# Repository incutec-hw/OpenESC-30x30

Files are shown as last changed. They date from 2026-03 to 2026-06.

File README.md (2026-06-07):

# OpenESC-30x30

Open-source 4-in-1 BLDC ESC with a 30.5 × 30.5 mm mounting pattern, built around four independent AT32F421 motor controllers running AM32. Six-layer, DShot over the standard 8-pin connector. Designed in KiCad for JLCPCB assembly.

<p>
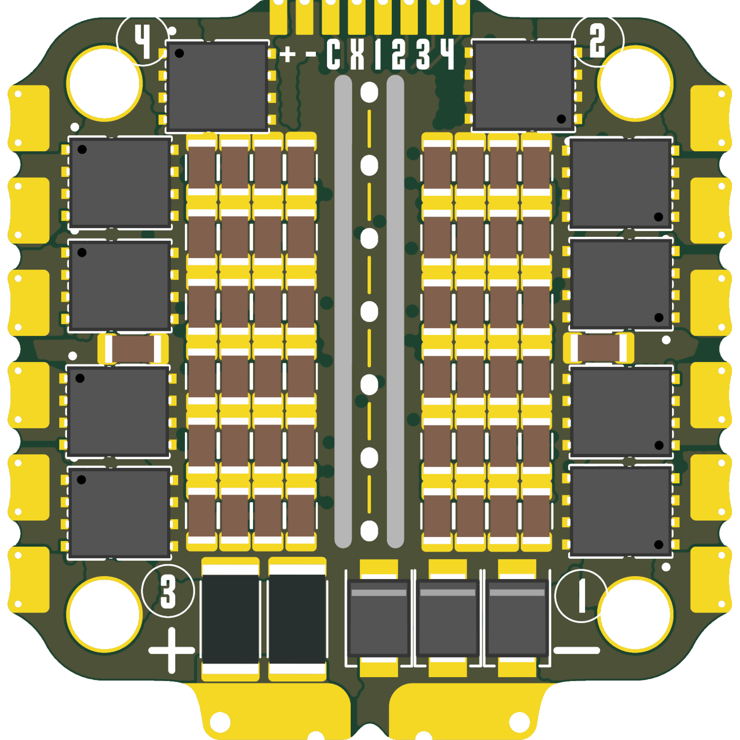
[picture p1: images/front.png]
OpenESC-30x30 top

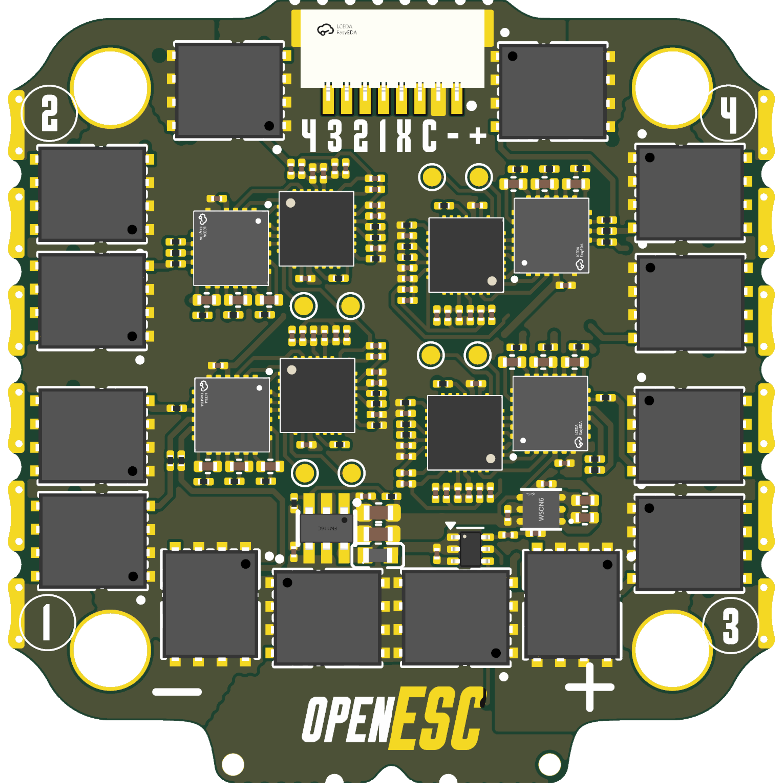
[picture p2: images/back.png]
OpenESC-30x30 bottom

</p>

Part of the incutec OpenDrone line (`incutec-hw/OpenESC-30x30`).

> A smaller **[OpenESC_20X20](https://github.com/incutec-hw/OpenESC_20X20)** (20×20 mm) shares this design and mirrors this repo. The two differ only in board/mounting size and a few power-stage parts.

## Architecture

Four fully independent ESC channels share a common power input and telemetry connector. Each channel has its own MCU and gate driver; the high-current stage is six MOSFETs per channel (three half-bridges). This is the distributed-MCU AM32 4-in-1 topology rather than a single-MCU design. Values below are extracted from the KiCad design files (`hardware/4in1.kicad_sch`, `hardware/ESC.kicad_sch`, `hardware/4in1.kicad_pcb`) and the production BOM (`hardware/production/Rev1-30x30_bom.csv`).

| Block | Part | LCSC | Per board |
|---|---|---|---|
| Motor MCU | AT32F421G8U7 (QFN-28) | C2765098 | 4 |
| Gate driver | NSG2065Q (QFN-24) | C41414478 | 4 |
| Power MOSFETs | SP40N01GHNK PDFN-8L (5×6) | C22385416 | 24 (6 per channel) |

## Specifications

| Parameter | Value |
|---|---|
| Channels | 4 independent BLDC channels |
| MCU | AT32F421G8U7 (ARM Cortex-M4, QFN-28), one per channel |
| Gate driver | NSG2065Q (QFN-24, FD6288Q-compatible), one per channel |
| Power MOSFETs | SP40N01GHNK, N-channel, PDFN-8L (5×6), 24 total (XRS280N03C selected as drop-in next-gen — not yet swapped) |
| Current sense | Board-level high-side: INA186A3IDCKR (100 V/V, SC-70-6) across 2× 0.2 mΩ 2512 shunts in parallel (0.1 mΩ) in the +BATT feed → 10 mV/A → ~330 A full-scale at 3.3 V ADC |
| Input | +BATT direct from connector/pads, 3S–6S |
| Input protection | 3× SMBJ24A TVS (24 V standoff) |
| Buck regulator | LMR54406DBVR (SOT-23-6) + FTC160808S4R7MBCA 4.7 µH inductor → +10 V gate-drive rail (FB 115k/10k, Vref 0.8 V → 10.0 V) |
| LDO | TLV76733DRVR (WSON-6) → +3V3 (MCUs, sensing), from +10 V |
| Signal protocol | DShot (4 independent signal lines, one per channel) |
| Firmware | AM32 (per-channel AT32F421 target, flashed individually) |
| PCB | 6-layer, 1.69 mm |
| Mounting pattern | 30.5 × 30.5 mm, 4× Ø4.0 mm holes (M3) |

Current/voltage ratings are not printed on the design files. The input clamp is set by the SMBJ24A TVS (24 V standoff → 3S–6S); the MOSFET (SP40N01GHNK) and current-sense full-scale (~330 A) set the practical envelope. Characterize before quoting a hard rating.

## Connector

8-pin JST **SM08B-SRSS-TB** (J1). Pin-to-net mapping extracted from the schematic (net labels at the connector pins):

| Pin | Net | Function |
|---|---|---|
| 1 | +BATT | Battery positive |
| 2 | GND | Ground |
| 3 | /CURR | Current-sense telemetry (INA186 output) |
| 4 | *(unconnected)* | No dedicated telemetry pin — telemetry handled by extended DShot |
| 5 | /M1 | DShot signal, channel 1 |
| 6 | /M2 | DShot signal, channel 2 |
| 7 | /M3 | DShot signal, channel 3 |
| 8 | /M4 | DShot signal, channel 4 |

Connector ground returns on the shield/mounting pads P1/P2 (both GND). The same eight signals are also broken out as direct solder pads (U3). Pin 4 — the dedicated telemetry pin on the Betaflight 8-pin standard — is intentionally unconnected: ESC→FC telemetry is carried over the motor signal lines via the bidirectional **extended DShot** protocol.

## Variants and revisions

| File | Description |
|---|---|
| `hardware/4in1.kicad_pro` / `.kicad_pcb` / `.kicad_sch` | Main design (30×30). |
| `hardware/4in1-panel.kicad_pro` / `.kicad_pcb` | Panelized version for production fabrication. |

This repo is the 30×30 member of the OpenESC family; the 20×20 sibling lives in [`OpenESC_20X20`](https://github.com/incutec-hw/OpenESC_20X20). Production exports in `hardware/production/` are versioned `V0.1`–`V0.4` and `Rev1`. `Rev1-30x30` is the 30×30-only fabrication set; `Rev1-30x3020x20` is a combined shared-fab set produced alongside the mini.

## Firmware

[AM32](https://github.com/AlkaMotors/AM32-MultiRotor-ESC-firmware) — incutec's default ESC firmware. Boards ship with the AM32 bootloader pre-loaded; firmware is flashed and configured in-browser at [am32.ca](https://am32.ca). Each channel's AT32F421G8U7 is an independent AM32 target. The AT32F421 + NSG2065Q per-channel topology and the DShot signal nets are the standard AM32 4-in-1 hardware target. Works with Betaflight and other DShot-capable flight controllers.

## Repository structure

```
README.md  LICENSE  CLAUDE.md            Repo root: docs + license + agent instructions
images/                                  Board render images
licensing/                               Hardware license, third-party notices, trademark policy
hardware/                                KiCad 9 project (everything to build/fab the board)
├── 4in1.kicad_sch                       Top schematic (power, current sense, connector)
├── ESC.kicad_sch                        Single ESC channel sheet (instantiated 4×)
├── 4in1.kicad_pcb                       Main board layout (6-layer)
├── 4in1.kicad_pro                       Main project
├── 4in1-panel.kicad_pcb / .kicad_pro    Panelized layout/project for production
├── components.kicad_sym                 Project-local symbol library
├── 4in1ESC-30x30.pretty/                Project-local footprints
├── 4in1ESC-30x30.3dshapes/             3D models (STEP)
├── fp-lib-table / sym-lib-table         Project-local library tables (${KIPRJMOD})
├── 4in1.step / 4in1.glb                 Exported board 3D models
├── production/                          JLCPCB fabrication exports (gerbers, BOM, CPL) per revision
├── fabrication-toolkit-options.json     KiCad Fabrication Toolkit settings
├── cost-analysis.md                     JLCPCB 500-unit cost breakdown (predates latest BOM)
└── database/                            Component analysis notes
```

## License

Hardware: [CERN-OHL-S-2.0](https://ohwr.org/cern_ohl_s_v2.txt). See [LICENSE](LICENSE), [licensing/THIRD_PARTY.md](licensing/THIRD_PARTY.md), and [licensing/TRADEMARKS.md](licensing/TRADEMARKS.md). Some bundled 3D model assets carry their own upstream notices (CC-BY-SA-4.0 / GPL).

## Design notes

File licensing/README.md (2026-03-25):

# Licensing Notes

This folder collects the repository-specific licensing and branding notes that sit alongside the root [LICENSE](../LICENSE) file.

Repository scope:

- Open 4-in-1 AM32 ESC 30x30 hardware design files
- local footprints, symbols, and manufacturing data included in this repository

Primary project hardware license:

- `CERN-OHL-S-2.0` for the primary Open 4-in-1 AM32 ESC 30x30 design and associated original project files

Related notes:

- [TRADEMARKS.md](TRADEMARKS.md) for branding and source-identifying use
- [THIRD_PARTY.md](THIRD_PARTY.md) for bundled upstream asset notices

The main `LICENSE` stays at the repository root so GitHub can detect the primary project license correctly.

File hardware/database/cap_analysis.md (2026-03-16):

# 10µF 50V 1206 MLCC — Cost & Performance Analysis

## Context
- 60× 1206 caps on the 30x30 board (MOSFET bulk decoupling on +BATT rail)
- Operating voltage: 11.1–25.2V (3S–6S LiPo)
- Current part: GCM31CD71H106KE36L (Murata X7T, C5119295)
- All caps derate heavily at 25V DC bias — dielectric type matters less than expected

## DC Bias Reality (25V bias on 50V-rated 1206 10µF)

Samsung published data from their product tool (measured at 1kHz, 25°C):
- **X5R 10µF 50V 1206**: -87% → ~1.3µF effective
- **X7R 10µF 50V 1206**: -78% → ~2.2µF effective

Murata X7T performs similarly per Stan's assessment — expect ~2–3µF effective at 25V.
Bottom line: **all 10µF 50V 1206 MLCCs give only ~2–3µF at operating voltage.**

## Candidate Parts — 10µF 50V 1206

| LCSC | MPN | Mfg | Dielectric | Stock | Basic | Qty 5 | Qty 60 | Qty 500 | 60× cost |
|---|-----|-----|---|---|---|---|---|---|---|
| C5119295 | GCM31CD71H106KE36L | Murata | X7T | 2,319 | No | $0.342 | $0.342 | $0.279 | **$20.52** |
| C89632 | CL31B106KBHNNNE | Samsung | X7R | 1,011,829 | No | $0.051 | $0.051 | $0.041 | **$3.07** |
| C303950 | 1206B106K500NT | FH | X7R | 388,847 | No | $0.068 | $0.068 | $0.055 | **$4.07** |
| C5449000 | TCC1206X7R106K500HT | CCTC | X7R | 44,779 | No | $0.038 | $0.038 | $0.031 | **$2.30** |
| **C13585** | **CL31A106KBHNNNE** | **Samsung** | **X5R** | **3,941,714** | **Yes** | **$0.028** | **$0.028** | — | **$1.67** |

## Current 0805 Part for Reference

| LCSC | MPN | Mfg | Dielectric | Stock | Basic | 60× cost |
|---|-----|-----|---|---|---|---|
| C440198 | GRM21BR61H106KE43L | Murata | X5R | 5,318,712 | Yes | $3.49 |

Note: 0805 has worse DC bias than 1206 (smaller dielectric volume).

## Recommendation

**C13585 (CL31A106KBHNNNE)** — Samsung X5R 10µF 50V 1206

- **$1.67 for 60 pcs** vs $20.52 for Murata X7T → **12× cheaper**
- 3.9M stock — no supply risk
- **JLCPCB basic part** — no $3 extended setup fee per unique part
- DC bias performance: ~1.3µF at 25V — slightly worse than X7R's ~2.2µF
- For bulk MOSFET decoupling, absolute capacitance matters less than ESR/ESL

If the extra ~1µF effective capacitance from X7R matters:
**C89632 (CL31B106KBHNNNE)** — Samsung X7R, $3.07 for 60, 1M stock, extended part

## Total BOM Impact (60 caps)

| Option | Part cost | Setup fee | Total | vs Murata X7T |
|---|---|---|---|---|
| GCM31CD71H106KE36L (current) | $20.52 | $3.00 | $23.52 | baseline |
| CL31A106KBHNNNE (X5R basic) | $1.67 | $0.00 | **$1.67** | **saves $21.85** |
| CL31B106KBHNNNE (X7R ext) | $3.07 | $3.00 | $6.07 | saves $17.45 |
| TCC1206X7R106K500HT (X7R ext) | $2.30 | $3.00 | $5.30 | saves $18.22 |

## SMBJ26A TVS Diode Alternative

Current: C908802 (GOODWORK) — 208 pcs at JLCPCB assembly, 190 shortfall, extended, €0.65

| LCSC | MPN | Mfg | Stock | Price | Notes |
|---|-----|-----|---|---|---|
| **C123820** | SMBJ26A | MDD | 22,554 | $0.051 | Best stock, reliable mfg |
| C353371 | SMBJ26A | Shandong Jingdao | 12,930 | $0.034 | Cheapest |
| C315992 | SMBJ26A | Littelfuse | 4,296 | $0.086 | Brand name |

All are identical spec: 26V standoff, 28.9V breakdown, 42.1V clamp, 600W peak, SMB package.
Recommend **C123820** (MDD) — 22k+ stock, $0.051, proven JLCPCB supplier.

---
*Generated 2026-03-15*

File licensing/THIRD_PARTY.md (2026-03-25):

# Third-Party Assets

This repository's main hardware design is licensed under `CERN-OHL-S-2.0`, but some bundled assets may retain their own upstream notices or licenses.

Known third-party-licensed assets observed in the current repo state:

- `4in1ESC-30x30.3dshapes/IND-SMD_L1.6-W0.8_FTC160865SR47MBCA.step`
  - contains an embedded `CC-BY-SA 4.0` notice and KiCad exception text in the file header
- `4in1ESC-30x30.3dshapes/QFN-28_L4.0-W4.0-P0.40-TL-EP2.4.step`
  - contains an embedded GNU General Public License notice in the file header

Practical rule:

- embedded upstream notices in individual third-party files remain relevant for those files
- the repository-level hardware license does not erase or replace those upstream notices

If more third-party library assets are intentionally bundled later, document them here.

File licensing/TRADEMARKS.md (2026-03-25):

# Trademarks And Branding

The primary Open 4-in-1 ESC 30x30 hardware design in this repository is licensed under `CERN-OHL-S-2.0`.

Some bundled third-party assets may carry separate upstream notices. See [THIRD_PARTY.md](THIRD_PARTY.md).

That hardware license does **not** grant permission to use any project names, logos, packaging, product branding, or other source-identifying presentation from this repository in a way that implies official status, endorsement, certification, or authorization.

This means you may:

- make, modify, and sell hardware based on the licensed design files, subject to the repository license
- use factual, non-confusing descriptive statements about compatibility or design origin

This means you may not, without separate written permission:

- present your product as an official or authorized version of this project
- use project logos or branded packaging
- market your product in a way that is likely to confuse customers about who made it, tested it, certified it, or supports it

Examples of descriptive use that are generally acceptable:

- `based on the Open 4-in-1 AM32 ESC design`
- `compatible with the 30x30 Open 4-in-1 AM32 ESC layout`

Any permission to use branding for an official product, reseller arrangement, or certification program is separate from the open hardware license.

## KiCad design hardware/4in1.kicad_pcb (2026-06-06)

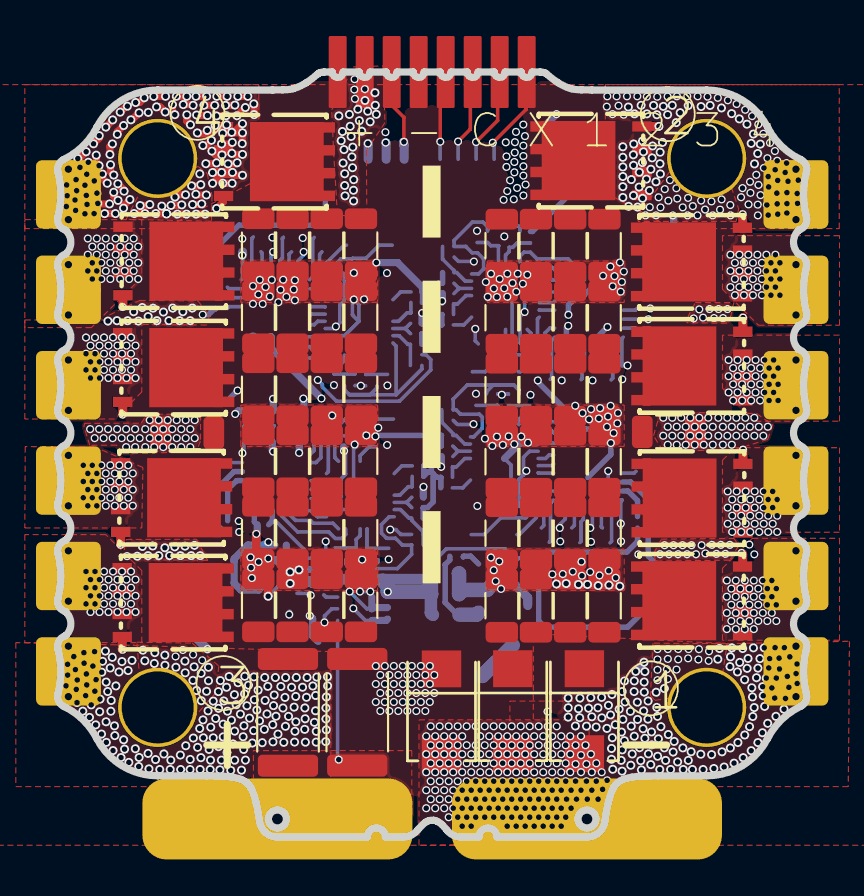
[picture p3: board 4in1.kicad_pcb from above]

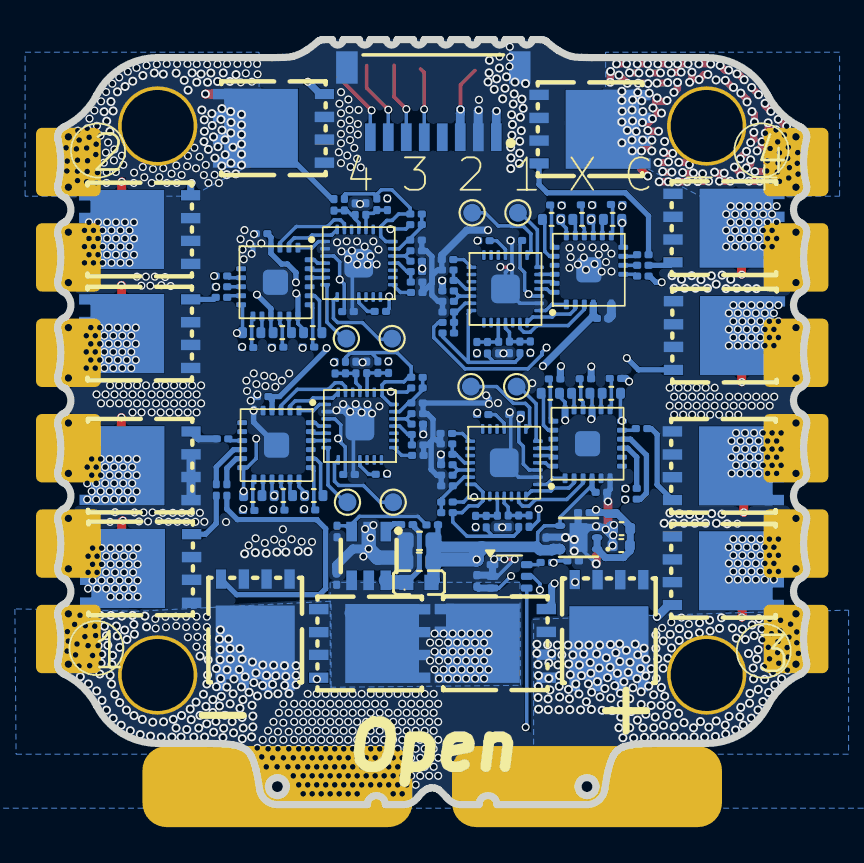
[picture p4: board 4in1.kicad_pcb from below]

Board: 6 copper layers, 41.6 x 42.5 mm, 218 parts (152 on the bottom side), 150 nets.

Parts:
C2, C3, C6, C6#2, C6#3, C7, C8, C9, C13, C14, C15, C16, C17, C18, C19, C20, C24, C25, C26, C27, C28, C29, C30, C31, C43, C44, C45, C69, C70, C71, C72, C79, C80, C82, C83, C84, C85, C87, C88, C95, C96, C97, C98, C99, C100, C101, C105, C106, C107, C108: 10uF; C_1206_3216Metric
C4, C51: 22uF; C_0402_1005Metric
C32, C33, C34, C35, C36, C37, C38, C39, C53, C56, C62, C67: 100nF; C_0402_WIDE
C47, C86: 22uF; C_0603_1608Metric
C48, C49, C50, C52, C54, C55, C57, C58, C59, C60, C61, C63, C64, C65, C66, C68, C74, C75, C76, C81, C93, C94: 100nF; C_0201_0603Metric
D1, D2, D3: SMBJ24A; SMB_L4.5-W3.7-LS5.4-RD
J1: SM08B-SRSS-TB; JST_SM08B-SRSS-TB
Q1, Q2, Q3, Q4, Q5, Q6, Q7, Q8, Q9, Q10, Q11, Q12, Q13, Q14, Q15, Q16, Q17, Q18, Q19, Q20, Q21, Q22, Q23, Q24: C22385416; PDFN-8L_L6.0-W5.0-P1.27
R10, R12, R13, R15, R25, R27, R28, R30, R31, R33, R34, R36, R46, R48, R49, R51, R52, R54, R64, R66, R67, R69, R70, R72: 10k; C_0201_0603Metric
R11, R14, R26, R29, R32, R35, R47, R50, R53, R65, R68, R71, R73: 1k; C_0201_0603Metric
R18, R19, R21, R22, R40, R41, R58, R59, R121: 10k; R_0201_0603Metric
R20, R39, R57, R87: 220R; R_0201_0603Metric
R23, R24, R37, R38, R42, R43, R44, R45, R55, R56, R60, R61, R62, R63, R74, R75, R76, R77, R78, R79, R80, R81, R82, R83: 15R; R_0201_0603Metric
R84, R85, R86, R88: 10R; R_0201_0603Metric
R120: 115k; R_0201_0603Metric
Rsense1, Rsense2: 0.2mR; R_2512_6332Metric
TP1, TP2, TP3, TP4, TP5, TP6, TP7, TP8: TestPoint; TestPoint_Pad_D1.0mm
U2, U5, U7, U9: AT32F421G8U7; QFN-28_L4.0-W4.0-P0.40-TL-EP2.4
U3: 4in1ESC30x30
U4, U6, U8, U10: NSG2065Q; QFN-24_L4.0-W4.0-P0.50-TL-EP2.8
U12: INA186A3IDCKR; SOT-363_SC-70-6
U13: LMR54406DBVR; SOT-23-6_L2.9-W1.6-P0.95-LS2.8-BR
U14: FTC160808S4R7MBCA; IND-SMD_L1.6-W0.8_FTC160865SR47MBCA
U15: TLV76733DRVR; WSON-6_L2.0-W2.0-P0.65-TL-EP

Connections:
+3V3: C4.2, C49.1, C51.2, C55.1, C61.1, C66.1, C81.1, C93.1, R18.2, R21.2, R40.2, R58.2, R84.2, R85.2, R86.2, R88.2, U2.17 (VDD), U5.17 (VDD), U7.17 (VDD), U9.17 (VDD), U12.3 (VS), U15.1 (OUT), U15.2 (FB/SNS)
+10V: C47.1, C57.1, C58.1, C63.1, C68.1, C76.1, C86.1, R120.1, U4.4 (VCC), U6.4 (VCC), U8.4 (VCC), U10.4 (VCC), U14.2, U15.4 (EN), U15.6 (IN)
+BATT: C2.1, C3.1, C6.1, C6#2.1, C6#3.1, C7.1, C8.1, C9.1, C13.1, C14.1, C15.1, C16.1, C17.1, C18.1, C19.1, C20.1, C24.1, C25.1, C26.1, C27.1, C28.1, C29.1, C30.1, C31.1, C43.1, C44.1, C45.1, C69.1, C70.1, C71.1, C72.1, C74.1, C79.1, C80.1, C82.1, C83.1, C84.1, C85.1, C87.1, C88.1, C95.1, C96.1, C97.1, C98.1, C99.1, C100.1, C101.1, C105.1, C106.1, C107.1, C108.1, D1.1, D2.1, D3.1, J1.1, Q1.3 (D), Q6.3 (D), Q7.3 (D), Q8.3 (D), Q9.3 (D), Q10.3 (D), Q13.3 (D), Q16.3 (D), Q17.3 (D), Q18.3 (D), Q19.3 (D), Q20.3 (D), Rsense1.2, Rsense2.2, U3.3 (VBAT+), U12.5 (-IN), U13.4 (EN), U13.5 (VIN)
/CSA+: Rsense1.1, Rsense2.1, U3.1 (VBAT), U12.4 (+IN)
/CURR: C94.1, J1.3, R73.1, U3.5 (CUR)
/ESC1/AH: U2.20 (PA10), U4.22 (HIN1)
/ESC1/AL: U2.15 (PB1), U4.1 (LIN1)
/ESC1/BH: U2.19 (PA9), U4.23 (HIN2)
/ESC1/BL: U2.14 (PB0), U4.2 (LIN2)
/ESC1/CH: U2.18 (PA8), U4.24 (HIN3)
/ESC1/CL: U2.13 (PA7), U4.3 (LIN3)
/ESC1/FBA: R25.1, R26.2, R27.2, U2.6 (PA0)
/ESC1/FBB: R28.2, R29.2, R30.2, U2.10 (PA4)
/ESC1/FBC: R31.2, R32.2, R33.2, U2.11 (PA5)
/ESC1/FBCOMMON: R25.2, R28.1, R31.1, U2.7 (PA1)
/ESC1/GHA: R76.1, U4.19 (HO1)
/ESC1/GHB: R55.1, U4.16 (HO2)
/ESC1/GHC: R23.1, U4.13 (HO3)
/ESC1/GLA: R80.1, U4.11 (LO1)
/ESC1/GLB: R62.1, U4.10 (LO2)
/ESC1/GLC: R42.1, U4.9 (LO3)
/ESC1/MotorA: C53.1, Q1.1 (S), Q2.3 (D), R27.1, U3.23 (1A), U4.18 (VS1)
/ESC1/MotorB: C32.1, Q6.1 (S), Q11.3 (D), R30.1, U3.22 (1B), U4.15 (VS2)
/ESC1/MotorC: C36.1, Q16.1 (S), Q21.3 (D), R33.1, U3.21 (1C), U4.12 (VS3)
/ESC1/vdda: C48.1, R84.1, U2.5 (VDDA)
/ESC2/AH: U5.20 (PA10), U6.22 (HIN1)
/ESC2/AL: U5.15 (PB1), U6.1 (LIN1)
/ESC2/BH: U5.19 (PA9), U6.23 (HIN2)
/ESC2/BL: U5.14 (PB0), U6.2 (LIN2)
/ESC2/CH: U5.18 (PA8), U6.24 (HIN3)
/ESC2/CL: U5.13 (PA7), U6.3 (LIN3)
/ESC2/FBA: R10.1, R11.2, R12.2, U5.6 (PA0)
/ESC2/FBB: R13.2, R14.2, R15.2, U5.10 (PA4)
/ESC2/FBC: R34.2, R35.2, R36.2, U5.11 (PA5)
/ESC2/FBCOMMON: R10.2, R13.1, R34.1, U5.7 (PA1)
/ESC2/GHA: R77.1, U6.19 (HO1)
/ESC2/GHB: R56.1, U6.16 (HO2)
/ESC2/GHC: R24.1, U6.13 (HO3)
/ESC2/GLA: R81.1, U6.11 (LO1)
/ESC2/GLB: R63.1, U6.10 (LO2)
/ESC2/GLC: R43.1, U6.9 (LO3)
/ESC2/MotorA: C56.1, Q3.3 (D), Q7.1 (S), R12.1, U3.20 (2B), U6.18 (VS1)
/ESC2/MotorB: C33.1, Q8.1 (S), Q12.3 (D), R15.1, U3.19 (2C), U6.15 (VS2)
/ESC2/MotorC: C37.1, Q17.1 (S), Q22.3 (D), R36.1, U3.18 (2A), U6.12 (VS3)
/ESC2/vdda: C54.1, R85.1, U5.5 (VDDA)
/ESC3/AH: U7.20 (PA10), U8.22 (HIN1)
/ESC3/AL: U7.15 (PB1), U8.1 (LIN1)
/ESC3/BH: U7.19 (PA9), U8.23 (HIN2)
/ESC3/BL: U7.14 (PB0), U8.2 (LIN2)
/ESC3/CH: U7.18 (PA8), U8.24 (HIN3)
/ESC3/CL: U7.13 (PA7), U8.3 (LIN3)
/ESC3/FBA: R46.1, R47.2, R48.2, U7.6 (PA0)
/ESC3/FBB: R49.2, R50.2, R51.2, U7.10 (PA4)
/ESC3/FBC: R52.2, R53.2, R54.2, U7.11 (PA5)
/ESC3/FBCOMMON: R46.2, R49.1, R52.1, U7.7 (PA1)
/ESC3/GHA: R78.1, U8.19 (HO1)
/ESC3/GHB: R60.1, U8.16 (HO2)
/ESC3/GHC: R37.1, U8.13 (HO3)
/ESC3/GLA: R82.1, U8.11 (LO1)
/ESC3/GLB: R74.1, U8.10 (LO2)
/ESC3/GLC: R44.1, U8.9 (LO3)
/ESC3/MotorA: C62.1, Q4.3 (D), Q13.1 (S), R48.1, U3.15 (3B), U8.18 (VS1)
/ESC3/MotorB: C34.1, Q9.1 (S), Q14.3 (D), R51.1, U3.16 (3C), U8.15 (VS2)
/ESC3/MotorC: C38.1, Q18.1 (S), Q23.3 (D), R54.1, U3.17 (3A), U8.12 (VS3)
/ESC3/vdda: C60.1, R86.1, U7.5 (VDDA)
/ESC4/AH: U9.20 (PA10), U10.22 (HIN1)
/ESC4/AL: U9.15 (PB1), U10.1 (LIN1)
/ESC4/BH: U9.19 (PA9), U10.23 (HIN2)
/ESC4/BL: U9.14 (PB0), U10.2 (LIN2)
/ESC4/CH: U9.18 (PA8), U10.24 (HIN3)
/ESC4/CL: U9.13 (PA7), U10.3 (LIN3)
/ESC4/FBA: R64.1, R65.2, R66.2, U9.6 (PA0)
/ESC4/FBB: R67.2, R68.2, R69.2, U9.10 (PA4)
/ESC4/FBC: R70.2, R71.2, R72.2, U9.11 (PA5)
/ESC4/FBCOMMON: R64.2, R67.1, R70.1, U9.7 (PA1)
/ESC4/GHA: R79.1, U10.19 (HO1)
/ESC4/GHB: R61.1, U10.16 (HO2)
/ESC4/GHC: R38.1, U10.13 (HO3)
/ESC4/GLA: R83.1, U10.11 (LO1)
/ESC4/GLB: R75.1, U10.10 (LO2)
/ESC4/GLC: R45.1, U10.9 (LO3)
/ESC4/MotorA: C67.1, Q5.3 (D), Q19.1 (S), R66.1, U3.12 (4A), U10.18 (VS1)
/ESC4/MotorB: C35.1, Q10.1 (S), Q15.3 (D), R69.1, U3.13 (4B), U10.15 (VS2)
/ESC4/MotorC: C39.1, Q20.1 (S), Q24.3 (D), R72.1, U3.14 (4C), U10.12 (VS3)
/ESC4/vdda: C65.1, R88.1, U9.5 (VDDA)
/M1: J1.5, R20.1, U3.7 (M1)
/M2: J1.6, R39.1, U3.8 (M2)
/M3: J1.7, R57.1, U3.9 (M3)
/M4: J1.8, R87.1, U3.10 (M4)
GND: C2.2, C3.2, C4.1, C6.2, C6#2.2, C6#3.2, C7.2, C8.2, C9.2, C13.2, C14.2, C15.2, C16.2, C17.2, C18.2, C19.2, C20.2, C24.2, C25.2, C26.2, C27.2, C28.2, C29.2, C30.2, C31.2, C43.2, C44.2, C45.2, C47.2, C48.2, C49.2, C50.2, C51.1, C52.2, C54.2, C55.2, C57.2, C58.2, C59.2, C60.2, C61.2, C63.2, C64.2, C65.2, C66.2, C68.2, C69.2, C70.2, C71.2, C72.2, C74.2, C76.2, C79.2, C80.2, C81.2, C82.2, C83.2, C84.2, C85.2, C86.2, C87.2, C88.2, C93.2, C94.2, C95.2, C96.2, C97.2, C98.2, C99.2, C100.2, C101.2, C105.2, C106.2, C107.2, C108.2, D1.2, D2.2, D3.2, J1.2, J1.P1 (MP1), J1.P2 (MP2), Q2.1 (S), Q3.1 (S), Q4.1 (S), Q5.1 (S), Q11.1 (S), Q12.1 (S), Q14.1 (S), Q15.1 (S), Q21.1 (S), Q22.1 (S), Q23.1 (S), Q24.1 (S), R11.1, R14.1, R19.2, R22.2, R26.1, R29.1, R32.1, R35.1, R41.2, R47.1, R50.1, R53.1, R59.2, R65.1, R68.1, R71.1, R121.2, U2.16 (VSS), U2.29 (VSS), U3.2 (BATGND), U3.4 (GND), U3.11 (Hole), U4.6 (COM), U4.25 (COM), U5.16 (VSS), U5.29 (VSS), U6.6 (COM), U6.25 (COM), U7.16 (VSS), U7.29 (VSS), U8.6 (COM), U8.25 (COM), U9.16 (VSS), U9.29 (VSS), U10.6 (COM), U10.25 (COM), U12.1 (REF), U12.2 (GND), U13.2 (GND), U15.3 (GND), U15.5 (GND), U15.7 (EP)
unnamed: Q1.2 (G), R76.2
unnamed: Q2.2 (G), R80.2
unnamed: Q3.2 (G), R81.2
unnamed: Q4.2 (G), R82.2
unnamed: Q5.2 (G), R83.2
unnamed: Q6.2 (G), R55.2
unnamed: Q7.2 (G), R77.2
unnamed: Q8.2 (G), R56.2
unnamed: Q9.2 (G), R60.2
unnamed: Q10.2 (G), R61.2
unnamed: Q11.2 (G), R62.2
unnamed: Q12.2 (G), R63.2
unnamed: Q13.2 (G), R78.2
unnamed: Q14.2 (G), R74.2
unnamed: Q15.2 (G), R75.2
unnamed: Q16.2 (G), R23.2
unnamed: Q17.2 (G), R24.2
unnamed: Q18.2 (G), R37.2
unnamed: Q19.2 (G), R79.2
unnamed: Q20.2 (G), R38.2
unnamed: Q21.2 (G), R42.2
unnamed: Q22.2 (G), R43.2
unnamed: Q23.2 (G), R44.2
unnamed: Q24.2 (G), R45.2
unnamed: R19.1, U2.1 (BOOT0)
unnamed: C50.1, R18.1, U2.4 (NRST)
unnamed: TP1.1 (1_1), U2.21 (PA13)
unnamed: TP4.1 (1_1), U2.22 (PA14)
unnamed: R20.2, U2.25 (PB4)
unnamed: C53.2, U4.20 (VB1)
unnamed: C32.2, U4.17 (VB2)
unnamed: C36.2, U4.14 (VB3)
unnamed: R22.1, U5.1 (BOOT0)
unnamed: C52.1, R21.1, U5.4 (NRST)
unnamed: TP2.1 (1_1), U5.21 (PA13)
unnamed: TP5.1 (1_1), U5.22 (PA14)
unnamed: R39.2, U5.25 (PB4)
unnamed: C56.2, U6.20 (VB1)
unnamed: C33.2, U6.17 (VB2)
unnamed: C37.2, U6.14 (VB3)
unnamed: R41.1, U7.1 (BOOT0)
unnamed: C59.1, R40.1, U7.4 (NRST)
unnamed: TP3.1 (1_1), U7.21 (PA13)
unnamed: TP6.1 (1_1), U7.22 (PA14)
unnamed: R57.2, U7.25 (PB4)
unnamed: C62.2, U8.20 (VB1)
unnamed: C34.2, U8.17 (VB2)
unnamed: C38.2, U8.14 (VB3)
unnamed: R59.1, U9.1 (BOOT0)
unnamed: C64.1, R58.1, U9.4 (NRST)
unnamed: TP7.1 (1_1), U9.21 (PA13)
unnamed: TP8.1 (1_1), U9.22 (PA14)
unnamed: R87.2, U9.25 (PB4)
unnamed: C67.2, U10.20 (VB1)
unnamed: C35.2, U10.17 (VB2)
unnamed: C39.2, U10.14 (VB3)
unnamed: R73.2, U12.6 (OUT)
unnamed: C75.2, U13.1 (CB)
unnamed: R120.2, R121.1, U13.3 (FB)
unnamed: C75.1, U13.6 (SW), U14.1

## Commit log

2026-03-11 Initial commit: 30x30 variant planning
    Hardware changes documented vs 20x20 variant.
    Key change: NSG20652Q gate driver (different pinout from NSG2065Q).
2026-03-11 Initial project setup from 20x20 variant
    Copied library, schematics, footprints, and 3D models from 20x20 project.
    Updated all paths for 30x30 project naming (footprint prefix, 3D model paths,
    project references). README documents hardware changes (NSG20652Q gate driver,
    SP40N01GHNK MOSFETs, 4-layer 30x30mm PCB).
    [4in1ESC-30x30.kicad_sch, ESC.kicad_sch]
2026-03-11 Sync v0.4 component changes from 20x20 variant
    - INA186A3IDCKR replaces INA199A1DCKR (current sense amp)
    - TLV76733DRVR replaces TPS746 (LDO), SNS wired to output
    - BLM03PX121SN1D ferrite bead on VDDA
    - Add .gitignore for backups and prl files
    [4in1ESC-30x30.kicad_sch, ESC.kicad_sch]
2026-03-14 Prepare for open source: PCB layout, new footprints, 3D models, comprehensive gitignore
    - Add PCB layout (4-layer, 30x30mm)
    - Add SP40N01GHNK MOSFET footprint and 3D model (PDFN-8L 5x6mm)
    - Add NSG20652Q gate driver alt footprint and QFN-24 3D model
    - Add board outline footprint and SMB connector footprint/3D model
    - Update schematic and symbols for NSG20652Q pinout
    - Comprehensive .gitignore matching 20x20 variant
    - Fix README link to 20x20 repo
    [4in1ESC-30x30.kicad_pcb, 4in1ESC-30x30.kicad_sch, ESC.kicad_sch]
2026-03-14 Switch gate driver to NSG2065Q (FD6288Q-compatible) in docs
    NSG20652Q was a dead-end with no pin-compatible alternatives.
    NSG2065Q shares the FD6288Q pinout with 7+ drop-in replacements
    and 27k+ combined LCSC stock. Same driver used in 20x20 variant.
2026-03-14 Update mounting pattern in README.md
2026-03-14 Add PCB render images to README
    Front and back 3D renders of the 30x30 board.
2026-03-16 Final parts changes and production files for V0.1
    [4in1ESC-30x30.kicad_pcb, 4in1ESC-30x30.kicad_sch, V0.1_bom.csv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]
2026-03-18 Replace backordered parts with in-stock LCSC alternatives
    - 10kΩ 0201: C473048 → C106225 (Yageo, 662k stock)
    - Ferrite bead 0201: C525479 → C440127 (330Ω@100MHz, better for VDDA filtering)
    - 220Ω 0201: C473535 → C226468 (Yageo)
    - 10uF cap: C440198 (0805) → C13585 (1206 basic part, Samsung)
    - TVS diode: C908802 → C315992 (Littelfuse SMBJ26A)
    [4in1ESC-30x30.kicad_pcb, 4in1ESC-30x30.kicad_sch, ESC.kicad_sch]
2026-03-25 Standardize repo: .gitignore, README, license, remove production from tracking
    - Standardize .gitignore to match ecosystem template
    - Update README: simplify license section, remove stale status checklist
    - Replace LICENSE stub with full CERN-OHL-S-2.0 text
    - Remove production/ from git tracking (generated, re-exportable)
    - Add previously untracked licensing/ directory
    - Delete empty nextpcb/ directory
    [4in1ESC-30x30.kicad_pcb, 4in1ESC-30x30.kicad_sch, ESC.kicad_sch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]
2026-05-07 alpha routing
    [4in1ESC-30x30.kicad_pcb, 4in1ESC-30x30.kicad_sch, ESC.kicad_sch]
2026-05-29 Migrate off iCloud and rename project to 4in1
    Moved repo from iCloud Drive to ~/OpenDrone/4in1. Renamed core KiCad
    project files (pro/sch/pcb/prl/dru) 4in1ESC-30x30 -> 4in1; updated
    .kicad_pro/.kicad_prl filenames, root sheet name, and the 74 footprint
    sheetfile hints in the PCB. Library dirs (.pretty/.3dshapes) kept as-is.
    Updated README/CLAUDE.md references. Checkpoint before 3D-model path fix.
    [4in1.kicad_pcb, 4in1.kicad_sch, 4in1ESC-30x30.kicad_pcb]
2026-05-29 Fix QFN 3D model paths to project-local 3dshapes
    The 7 QFN footprints (U2/U5/U7/U9 QFN-28, U4/U8/U10 QFN-24) had 3D
    model links inherited from the mini project: ${KIPRJMOD}/4in1ESC.3dshapes/
    or absolute paths into the old iCloud "4in1ESC 2" folder, neither of
    which resolve here. Repointed all to ${KIPRJMOD}/4in1ESC-30x30.3dshapes/
    (files already present) and fixed the same path in the QFN-24-TL-EP2.8
    and QFN-28 library footprints so library updates won't regress it.
    Total broken 3D refs: 0.
2026-06-06 docs: reconcile README to design files, add DESIGN_NOTES
    Reconcile README against schematic net labels and on-canvas comments:
    6-layer (was 4), LMR54406DBVR buck -> +10V (was LMR51420/12V),
    FTC160808 4.7uH inductor, board-level INA186 current sense (2x 0.2mR
    parallel -> ~330A), connector pin 4 unconnected, GND on pads P1/P2,
    drop the 20x20-on-same-layout claim (30x30 only). Note MOSFET Value/LCSC
    field swap (build = SP40N01GHNK/C22385416). Add DESIGN_NOTES.md mirroring
    on-canvas KiCad comments.
2026-06-06 docs: telemetry via extended DShot (pin 4), final canvas sync
2026-06-06 meta: standardize symbol BOM/doc fields (30x30)
    Add MPN/Manufacturer/LCSC/Digi-Key/Mouser/Farnell/Cost to every sourced
    part. Source MPN + LCSC unit cost via keyless LCSC; Manufacturer set for
    known ICs (TI, ArteryTek, Littelfuse). Fix MOSFET Value/LCSC swap
    (Value/MPN=SP40N01GHNK, LCSC=C22385416), clear legacy LCSC_Part, strip
    CJK from Manufacturer. Digi-Key/Mouser/Farnell left blank pending API
    creds. Properties-only — no connectivity change. Also carries the
    finalized on-canvas design comments.
    [4in1.kicad_sch, ESC.kicad_sch]
2026-06-06 pcb: routing snapshot (WIP) before hardware/ restructure
    Snapshot of in-progress PCB routing so the upcoming directory
    restructure can move the file as a clean rename. Routing is still
    in progress.
    [4in1.kicad_pcb]
2026-06-06 docs: refresh board renders (standardized 3D top/bottom)
    [4in1.kicad_pcb, 4in1.kicad_sch, ESC.kicad_sch]
2026-06-06 docs: update paths for hardware/ restructure (30x30)
    Repo restructured to mirror OpenFC-Lite: KiCad project + libs +
    production + design docs moved under hardware/; root keeps README,
    LICENSE, CLAUDE.md, images/, licensing/. Update README structure tree
    and all path references. (CLAUDE.md updated locally; it is git-ignored.)
    The git mv renames themselves were swept into the prior render commit
    79590e2; this commit fixes the doc references.
2026-06-06 docs: show board renders side-by-side (OpenFC-Lite-Mini style)
2026-06-07 docs: via-free board renders
    Re-render top/bottom board images with vias removed for a cleaner look.
    KiCad cannot render tented vias, so vias were temporarily stripped via the
    pcbnew API for rendering only; source .kicad_pcb files are unchanged.
2026-06-07 docs: re-render boards without floor shadows
    Re-render top/bottom images at basic quality so the soldermask floor
    shadow halo is gone. Vias still stripped for the render only (via pcbnew),
    source .kicad_pcb files unchanged.
2026-06-07 docs: render boards without solder paste
    Strip the solder-paste layer (and vias) for the render only so SMD pads
    show as clean copper instead of gray paste deposits. Source .kicad_pcb
    files unchanged.
2026-06-07 docs: remove DESIGN_NOTES, trim README boilerplate
    - Delete DESIGN_NOTES.md (and its gitignore exception)
    - Drop the Manufacturing / production-export section
    - Remove the canonical-reference boilerplate blurb
    - ESC boards: AM32 bootloader ships pre-loaded, firmware flashed via am32.ca
